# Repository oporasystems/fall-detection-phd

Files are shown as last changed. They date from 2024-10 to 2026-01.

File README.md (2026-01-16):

# Fall Detection System

A transformer-based fall detection system combining IoT sensors (Raspberry Pi + MPU6050 accelerometer) with deep learning for real-time fall classification. This project was developed as part of PhD research comparing multiple transformer architectures for time-series classification.

## Overview

The system collects accelerometer data at 100Hz, processes it through trained neural network models, and triggers alerts via a GPIO-connected buzzer when a fall is detected. After extensive comparison of 10 different transformer variants, the **Performer** architecture was selected for production deployment due to its optimal balance of accuracy and inference speed on embedded hardware.

### Key Features

- Real-time fall detection on Raspberry Pi Zero 2W
- 100Hz accelerometer sampling with Butterworth filtering
- Binary classification (Fall vs Activities of Daily Living)
- Sub-5MB model size for embedded deployment
- Audible alerts via piezo buzzer

## Hardware Requirements

| Component | Description |
|---|---|
| Raspberry Pi Zero 2W | Main processing unit |
| MPU6050 | 6-axis accelerometer/gyroscope (I2C address 0x68) |
| BMP388 | Barometric pressure sensor (for altitude) |
| Piezo Buzzer | Connected to GPIO 23 |
| Push Buttons | GPIO 24 (tracking on/off), GPIO 25 (alert on/off) |

### Wiring Diagram

```
MPU6050:
  VCC -> 3.3V
  GND -> GND
  SDA -> GPIO 2 (SDA)
  SCL -> GPIO 3 (SCL)

BMP388:
  VCC -> 3.3V
  GND -> GND
  SDA -> GPIO 2 (SDA)
  SCL -> GPIO 3 (SCL)

Buzzer:
  + -> GPIO 23
  - -> GND

Buttons:
  Button 1 -> GPIO 24 (with pull-up)
  Button 2 -> GPIO 25 (with pull-up)
```

## Quick Start (Raspberry Pi)

### 1. Install Dependencies

```bash
sudo apt install -y i2c-tools python3-pip
pip install pandas smbus numpy scikit-learn torch scipy RPi.GPIO \
    board Adafruit-Blinka adafruit-circuitpython-bmp3xx performer-pytorch \
    --break-system-packages
```

### 2. Enable I2C

```bash
sudo raspi-config
# Navigate to: Interface Options -> I2C -> Enable
```

### 3. Verify Sensors

```bash
i2cdetect -y 1
# Should show devices at 0x68 (MPU6050) and 0x77 (BMP388)
```

### 4. Deploy Model and Config Files

Copy to your Raspberry Pi:
- `performer_model.pt` -> `/home/ivanursul/performer_model.pt`
- `mpu_offsets.json` -> `/home/ivanursul/mpu_offsets.json`

### 5. Run Fall Detector

```bash
python3 iot/pi/fall-detector.py
```

### 6. Setup as Systemd Service (Optional)

Create service file:
```bash
sudo nano /etc/systemd/system/fall-detector.service
```

Contents:
```ini
[Unit]
Description=Fall Detection Service
After=network.target

[Service]
ExecStart=/usr/bin/python3 /home/ivanursul/fall-detector.py
Restart=always
WorkingDirectory=/home/ivanursul
Environment="PYTHONUNBUFFERED=1"

[Install]
WantedBy=multi-user.target
```

Enable and start:
```bash
sudo systemctl daemon-reload
sudo systemctl enable fall-detector.service
sudo systemctl start fall-detector.service
```

Check status:
```bash
sudo systemctl status fall-detector.service
journalctl -u fall-detector.service --no-pager --lines=50
```

## Project Structure

```
fall-detection-phd/
├── config.yaml                 # Base configuration (committed)
├── config.local.yaml.example   # Template for local overrides
├── deploy/                         # Deployment scripts
│   ├── common.sh                   # Shared deployment functions
│   ├── deploy-fall-detector.sh     # Deploy production fall detection
│   ├── deploy-adl-collector.sh     # Deploy ADL data collector
│   ├── deploy-fall-collector.sh    # Deploy fall data collector
│   └── logs.sh                     # View logs from Pi remotely
├── iot/
│   ├── pi/
│   │   ├── fall-detector.py        # Production fall detection (uses Performer)
│   │   ├── data-collector-adl.py   # Collect ADL (daily activities) data
│   │   ├── data-collector-falls.py # Collect fall data with timing heatmap
│   │   ├── calibrate-mpu-6050.py   # Sensor calibration utility
│   │   ├── logging_config.py       # Shared logging configuration
│   │   └── debug/                  # Debugging utilities
│   └── arduino/
│       └── converter/              # TFLite model conversion
├── training/
│   ├── models/                     # Model architecture definitions
│   │   ├── transformer.py          # Base transformer
│   │   ├── performer.py            # Performer (PRODUCTION MODEL)
│   │   ├── informer.py             # Sparse attention
│   │   ├── linformer.py            # Linear complexity
│   │   ├── multi_scale_transformer.py
│   │   ├── temporal_convolutional_transformer.py
│   │   ├── lstm_transformer.py
│   │   ├── t2v_bert.py             # Time2Vec + BERT
│   │   └── transformer_laurel.py   # LAuReL residual enhancement
│   ├── variations/                 # Training scripts per model
│   │   ├── performer/              # Performer training & tuning
│   │   ├── transformer/
│   │   ├── informer/
│   │   └── ...                     # Other variants
│   ├── experiments/                # Model comparison experiments
│   └── utils/
│       ├── constants.py            # Configuration loader
│       ├── dataset_utils.py        # Dataset loading
│       ├── train_utils.py          # Training utilities
│       └── logging_utils.py        # Logging setup
├── dataset/
│   ├── review/                     # Dataset review utilities
│   ├── visualisation/              # Visualization scripts
│   └── video/                      # Video-based dataset tools
├── 3d-models/                      # OpenSCAD enclosure designs
├── pcb/                            # Circuit board designs
└── docs/
    └── plans/                      # Design documents
```

## Model Architectures

This project implements and compares 10 transformer variants for fall detection:

| Model | Description | Key Feature |
|---|---|---|
| **Performer** | Kernel-based efficient attention | **Selected for production** - best accuracy/speed tradeoff |
| Transformer | Standard multi-head attention | Baseline implementation |
| Informer | ProbSparse self-attention | Reduced complexity for long sequences |
| Linformer | Linear complexity attention | O(n) instead of O(n²) |
| Multi-Scale | Multi-resolution processing | Captures patterns at different time scales |
| TCN-Transformer | Temporal convolution + transformer | Hybrid architecture |
| LSTM-Transformer | LSTM + transformer | Combines recurrent and attention |
| T2V-BERT | Time2Vec + BERT | Learned time representations |
| LAuReL | Residual enhancement | Latest experimental addition |
| Reformer | Local sensitive hashing | Memory-efficient attention |

### Why Performer?

After hyperparameter tuning with Optuna and comparison experiments, Performer was selected because:
1. Achieves comparable accuracy to standard transformer
2. Significantly faster inference on Raspberry Pi
3. Model size under 5MB constraint for embedded deployment
4. Stable training with good generalization

## Training Pipeline

### Dataset Format

The system expects CSV files with accelerometer data:
- **Columns**: `AccX_filtered_i`, `AccY_filtered_i`, `Corrected_AccZ_i`, `Acc_magnitude_i`
- **Sequence length**: 800 timesteps (8 seconds at 100Hz)
- **Labels**: Binary (0 = Non-Fall/ADL, 1 = Fall)

### Configuration

1. Copy the example config:
   ```bash
   cp config.local.yaml.example config.local.yaml
   ```

2. Edit `config.local.yaml` with your dataset paths:
   ```yaml
   dataset:
     fall_folder: "/path/to/your/Fall/data"
     non_fall_folder: "/path/to/your/ADL/data"
   ```

### Training a Model

```bash
# Train Performer model
python3 training/variations/performer/performer-model.py

# Run hyperparameter tuning
python3 training/variations/performer/performer-hyperparameter-tuning.py
```

### Model Comparison

The `training/experiments/transformer-variation-comparison/` directory contains scripts to evaluate all models on the same dataset, measuring:
- Accuracy, Precision, Recall, F1-score
- Inference latency
- Memory usage
- Model size

## Data Collection

### Activities of Daily Living (ADL)

```bash
python3 iot/pi/data-collector-adl.py
```

Collects 8-second windows of normal daily activities. Press the button (GPIO 24) to start/stop recording.

### Fall Data

```bash
python3 iot/pi/data-collector-falls.py
```

Collects fall event data with an intelligent timing system:
- Maintains a heatmap of when falls occur within the 8-second window
- Beeps to signal when to perform the fall
- Ensures balanced dataset distribution across all 100ms intervals

This approach prevents bias in fall timing and improves model generalization.

## Deployment

Automated deployment scripts make it easy to set up Raspberry Pi devices for your team.

### Prerequisites

Install `sshpass` on your local machine for automated SSH:

```bash
# macOS
brew install hudochenkov/sshpass/sshpass

# Ubuntu/Debian
sudo apt install sshpass
```

### Deploy Fall Detector (Production)

```bash
./deploy/deploy-fall-detector.sh
```

Deploys real-time fall detection:
- Uploads `fall-detector.py` and trained Performer model
- Runs sensor calibration
- Sets up auto-start systemd service

### Deploy ADL Data Collector

```bash
./deploy/deploy-adl-collector.sh
```

Deploys data collection for normal daily activities:
- Uploads `data-collector-adl.py`
- Runs sensor calibration
- Sets up systemd service

### Deploy Fall Data Collector

```bash
./deploy/deploy-fall-collector.sh
```

Deploys data collection for fall events:
- Uploads `data-collector-falls.py` and timing heatmap
- Runs sensor calibration
- Sets up systemd service

### Switching Modes

Only one mode can be active at a time. Deploying a new mode automatically stops and replaces the previous one:

1. Deploy `fall-collector` → collect fall data
2. Deploy `adl-collector` → collect daily activity data
3. Retrain model with new data
4. Deploy `fall-detector` → back to production

### Calibration

During deployment, you'll be prompted to position the device:

1. Place the device on a **flat, level surface**
2. Keep it **completely stationary**
3. Press ENTER to start calibration

The calibration measures accelerometer bias and saves offsets to `mpu_offsets.json`.

### Viewing Logs

Logs are stored in `~/logs/fall-detection.log` with daily rotation (30 days retention).

```bash
# View logs interactively
./deploy/logs.sh

# Follow logs in real-time
./deploy/logs.sh -f

# Show last 500 lines
./deploy/logs.sh -n 500

# Show logs from specific date
./deploy/logs.sh -d 2024-01-15
```

### Managing Services

```bash
# Check status
ssh pi@<IP> 'systemctl status fall-detector'

# Restart
ssh pi@<IP> 'sudo systemctl restart fall-detector'

# Stop
ssh pi@<IP> 'sudo systemctl stop fall-detector'
```

## Configuration Reference

### config.yaml

| Section | Key | Description |
|---|-----|---|
| `dataset.fall_folder` | Path to fall data CSVs |
| `dataset.non_fall_folder` | Path to ADL data CSVs |
| `model.max_sequence_length` | Input sequence length (default: 800) |
| `model.input_dim` | Number of input features (default: 4) |
| `model.num_classes` | Classification classes (default: 2) |
| `raspberry_pi.model_path` | Path to deployed model on Pi |
| `hardware.sampling_rate` | Sensor sampling rate (default: 100Hz) |

### config.local.yaml

Create this file (gitignored) to override base settings for your environment. Only include values that differ from the base config.

## Troubleshooting

### I2C Device Not Found

```bash
# Check if I2C is enabled
ls /dev/i2c*

# Scan for devices
i2cdetect -y 1
```

If devices aren't detected:
1. Check wiring connections
2. Ensure I2C is enabled in raspi-config
3. Verify pull-up resistors on SDA/SCL lines

### Model Loading Errors

- Ensure PyTorch version matches between training and deployment
- Verify model file path in config or fall-detector.py
- Check available memory on Raspberry Pi

### Buzzer Not Sounding

- Verify GPIO 23 connection
- Check if GPIO is being used by another process
- Test with a simple GPIO script

### High CPU Usage

The fall detector runs continuously. On Raspberry Pi Zero 2W:
- CPU usage ~60-80% during inference is normal
- Consider reducing sampling rate if overheating occurs

## License

This project was developed as part of PhD research. Please contact the author for licensing information.

## Citation

If you use this work in your research, please cite:
```
[Citation information to be added]
```

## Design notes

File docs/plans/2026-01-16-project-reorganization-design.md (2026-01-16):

# Fall Detection Project Reorganization Design

**Date:** 2026-01-16
**Status:** Approved
**Goal:** Archive cleanup, production focus, and team-ready GitHub release

## Context

This is a completed PhD project for transformer-based fall detection using Raspberry Pi and MPU6050 accelerometer. The **Performer** model was selected as the best-performing architecture and is deployed in production (`iot/pi/fall-detector.py`).

The project needs cleanup for:
- Academic archival (thesis/publication ready)
- Production deployment (Raspberry Pi)
- Team collaboration (GitHub release)

## Decisions Made

| Decision | Choice | Rationale |
|---|---|---|
| Chosen model | Performer | Best performance, already in production |
| Other model variants | Keep all | Preserve research history for reproducibility |
| IoT script refactoring | No | No tests, working code, risk of breaking |
| Path configuration | Config file (base + local override) | Team-friendly, explicit |
| Documentation | Full README | Comprehensive for onboarding |
| Reorganization scope | Quick wins only | Minimal disruption |

## Implementation Plan

### 1. Quick Win Fixes

#### 1.1 Remove duplicate code
- `training/models/multi_scale_transformer.py`: Delete duplicate `PositionalEncoding` class (lines 27-45)
- `training/utils/train_utils.py`: Remove duplicate `train_model()` function (lines 95-129)

#### 1.2 Update `.gitignore`
Add:
```
venv/
*.zip
.DS_Store
__pycache__/
*.pyc
config.local.yaml
```

#### 1.3 File naming
- Keep existing names as-is (no renaming)
- Document convention for future files: use underscores for Python files

### 2. Config File System

#### 2.1 Create `config.yaml` (committed)
Base config with defaults:
```yaml
# Base configuration - override in config.local.yaml
dataset:
  fall_folder: "./data/Fall"
  non_fall_folder: "./data/ADL"

raspberry_pi:
  model_path: "/home/ivanursul/performer_model.pt"
  offsets_path: "/home/ivanursul/mpu_offsets.json"
  data_output_path: "/home/ivanursul/accelerometer_data_raw"
```

#### 2.2 Create `config.local.yaml.example`
Template for personal overrides:
```yaml
# Copy to config.local.yaml and customize
dataset:
  fall_folder: "/your/path/to/Fall"
  non_fall_folder: "/your/path/to/ADL"
```

#### 2.3 Update `training/utils/constants.py`
Load base config, merge local overrides if present.

### 3. Documentation (README.md)

Structure:
1. Overview - Project description, key features
2. Hardware Requirements - Pi Zero 2W, MPU6050, BMP388, buzzer, buttons
3. Quick Start - Installation, systemd setup, running fall-detector.py
4. Project Structure - Directory tree with descriptions
5. Model Architectures - All 10 variants, why Performer was selected
6. Training Pipeline - Dataset format, training, hyperparameter tuning
7. Data Collection - ADL and falls scripts, heatmap system
8. Configuration - config.yaml vs config.local.yaml
9. Troubleshooting - Common issues

## What Stays Unchanged

- `iot/pi/data-collector-adl.py` - no refactoring
- `iot/pi/data-collector-falls.py` - no refactoring
- `iot/pi/fall-detector.py` - no refactoring
- Folder structure - no reorganization
- All 10 model variants - preserved as-is
- Existing file names - no renaming
- Training pipeline logic - unchanged

## Implementation Order

1. Fix `.gitignore` (prevents committing junk)
2. Remove duplicate code (quick fixes)
3. Add config file system
4. Write comprehensive README

## Deliverables

- Clean codebase with no duplicate code
- Config-based path management for team use
- Comprehensive README for onboarding
- All 10 model variants preserved with documentation

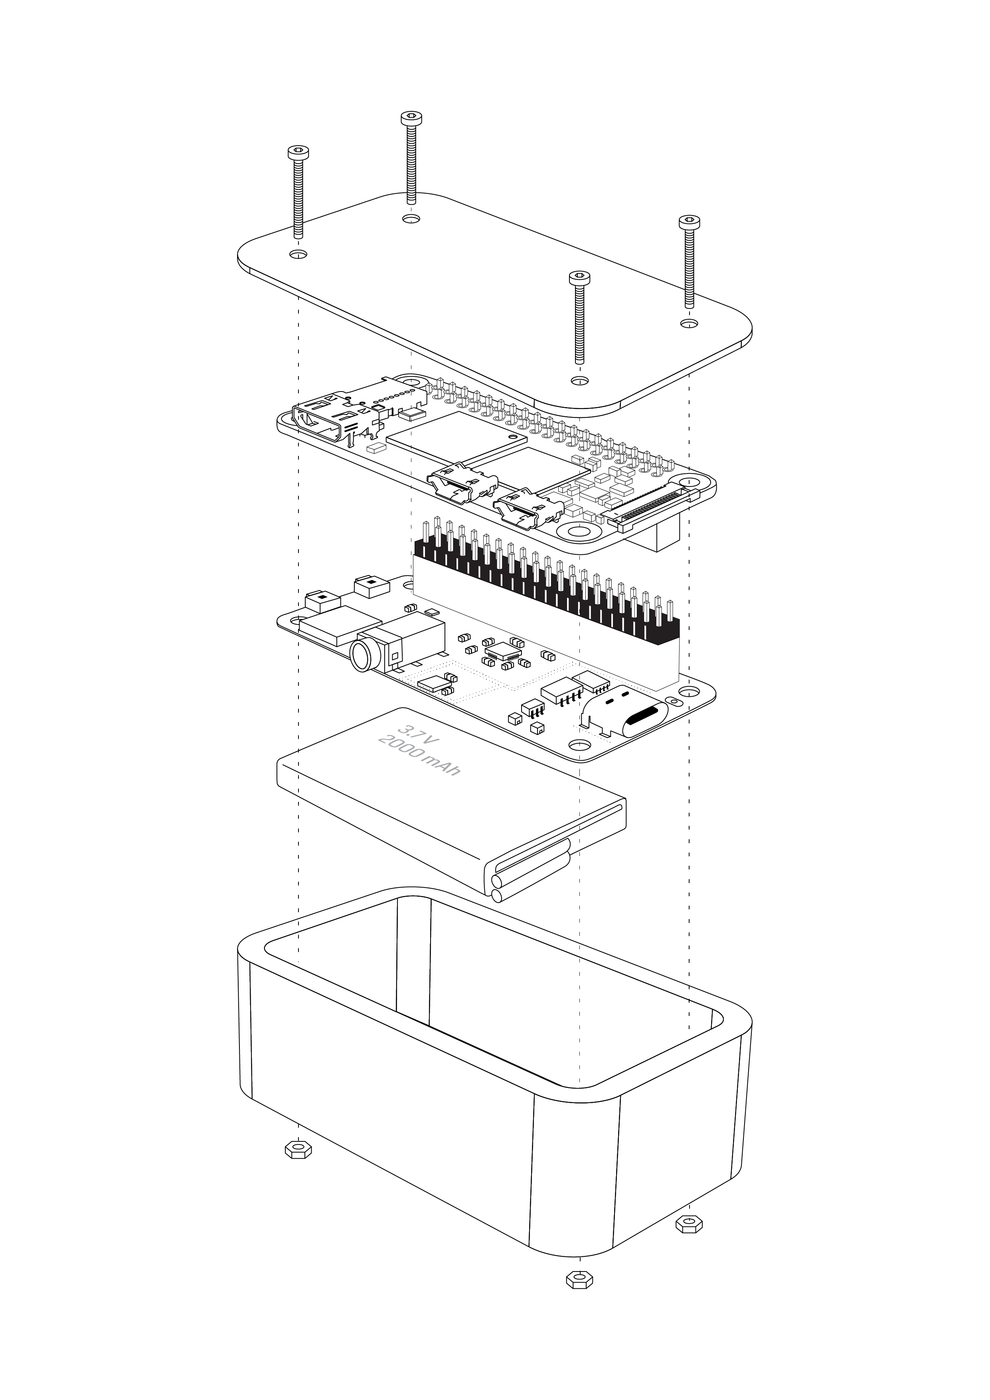
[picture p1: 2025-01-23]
Geriatric device-02.png

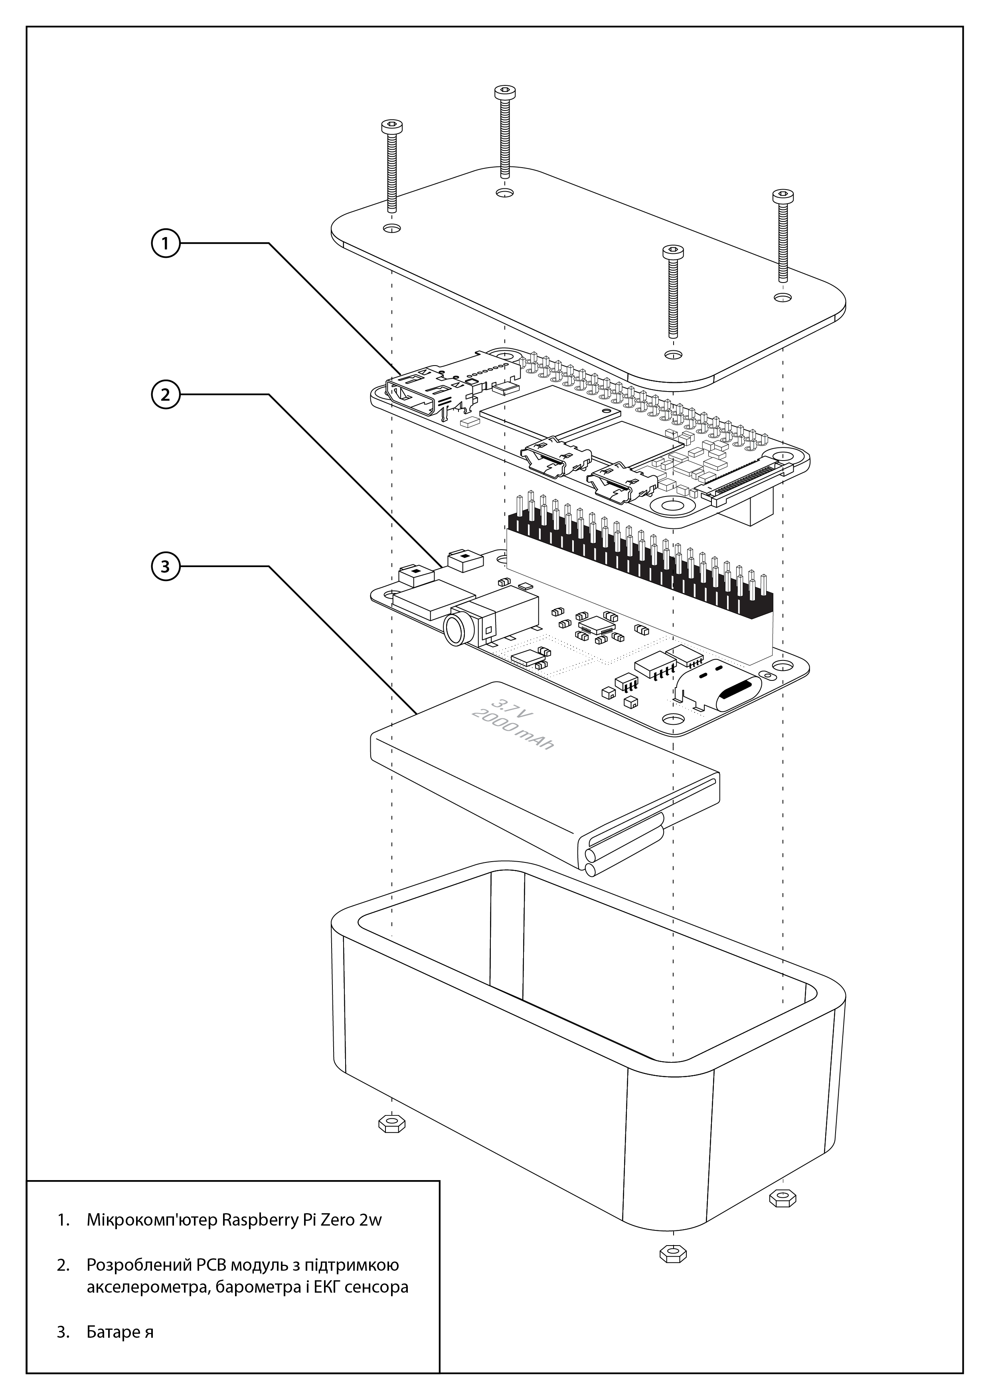
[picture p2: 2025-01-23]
Geriatric device-01.png

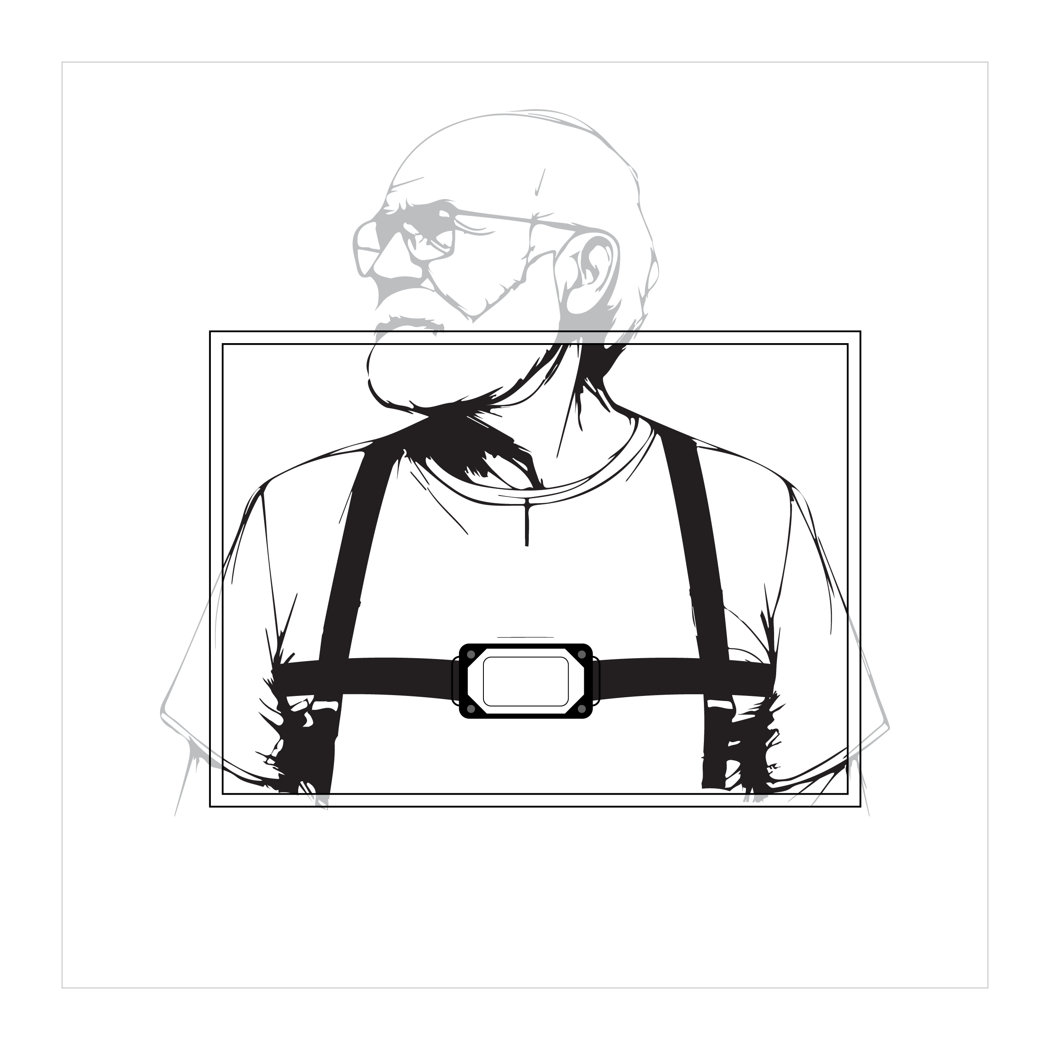
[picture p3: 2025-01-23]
Geriatric device-03.png

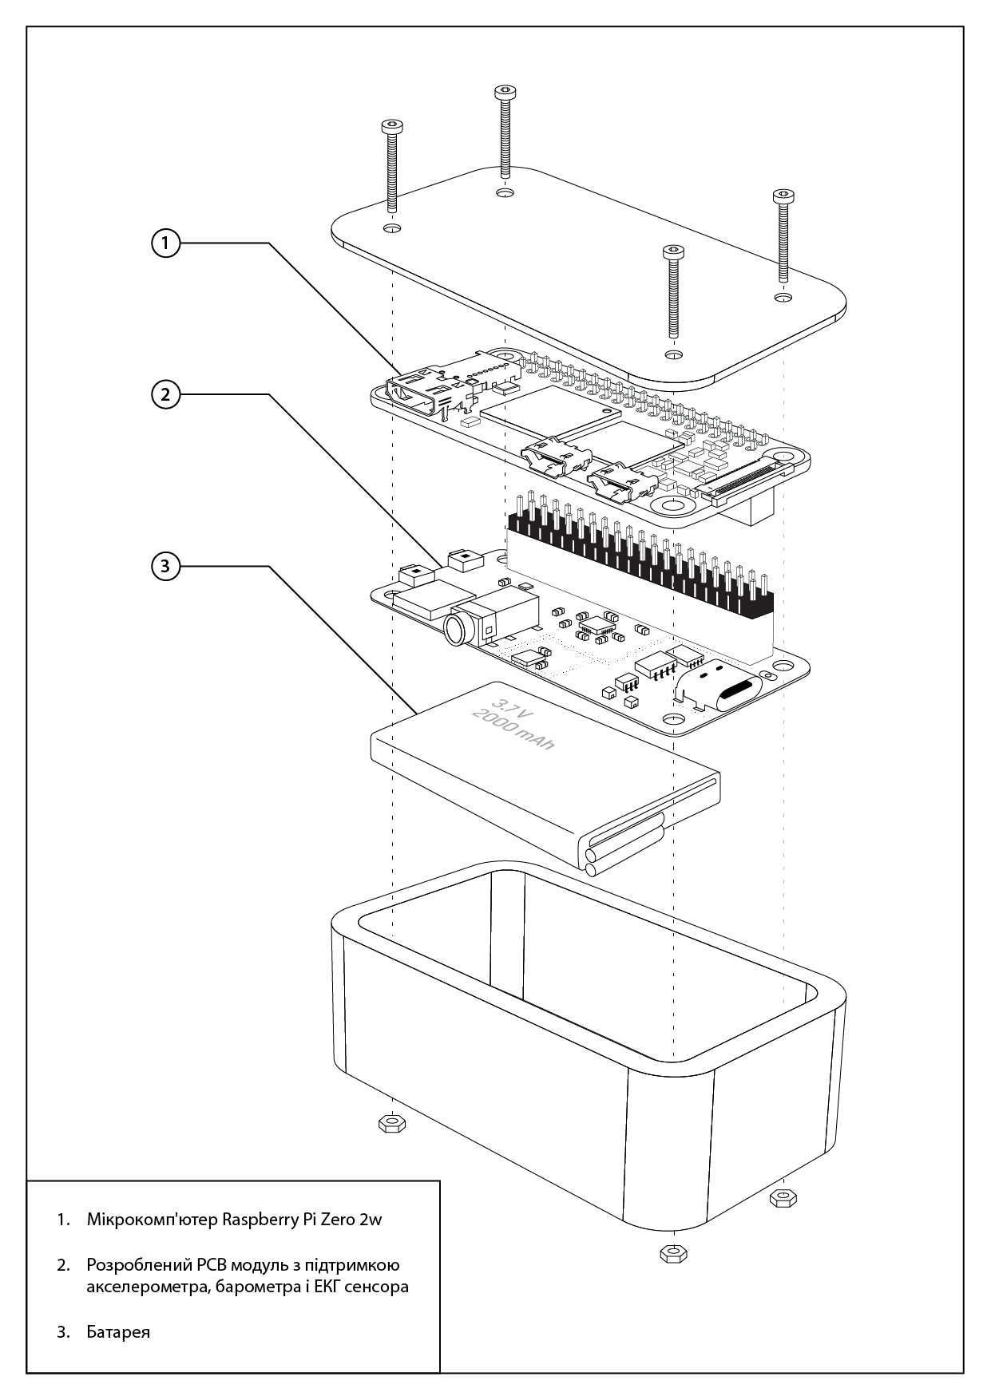
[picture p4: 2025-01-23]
patent blueprint-01.png

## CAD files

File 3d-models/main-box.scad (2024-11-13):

// Parameters
length = 76;            // Outer length of the box
width = 40;             // Outer width of the box
height = 25;            // Height of the box
wall_thickness = 2;     // Thickness of the walls (returned to 2mm)
corner_radius = 5;      // Radius of the outer corners

// USB Type-C hole parameters
usb_width = 10;         // Width of the USB Type-C hole
usb_height = 4;         // Height of the USB Type-C hole
usb_corner_radius = 1;  // Corner radius for the USB hole (optional)
usb_position_y = 0;     // Y position (centered vertically on the side wall)
usb_position_z = wall_thickness + usb_height / 2 + 10; // Near bottom edge

// Push button hole parameters
button_size = 6;        // Size of the push button holes (6mm x 6mm)
button1_position_x = -length / 4;  // Position of the first button hole
button2_position_x = length / 4;   // Position of the second button hole
button_position_z = (height / 2);    // Centered vertically

// New hole parameters
new_hole_width = 13;        // Width of the new hole (along the x-axis)
new_hole_height = 9;      // Height of the new hole (along the z-axis)
new_hole_position_x = 0;   // Position of the new hole along the x-axis (centered between existing holes)
new_hole_position_z = button_position_z + 3; // Vertical position (same as existing holes)

// Tolerance for proper subtraction
epsilon = 0.1;          // Small offset to ensure clean subtraction

// Calculate inner_corner_radius and handle corner_radius < wall_thickness
if (corner_radius < wall_thickness) {
    echo("Error: corner_radius must be greater than or equal to wall_thickness");
    corner_radius = wall_thickness; // Set corner_radius to wall_thickness to avoid negative values
}
inner_corner_radius = corner_radius - wall_thickness;

difference() {
    // Outer box with rounded corners
    linear_extrude(height)
        rounded_rectangle(length, width, corner_radius);

    // Inner box to create the hollow space
    translate([0, 0, wall_thickness])
        linear_extrude(height - wall_thickness)
            rounded_rectangle(length - 2 * wall_thickness, width - 2 * wall_thickness, inner_corner_radius);

    // USB Type-C hole on the longer side, near the bottom edge
    translate([length / 2 + epsilon, usb_position_y, usb_position_z])
        rotate([0, 0, 90]) // Rotate to align with the side wall
            usb_hole();

    // Push button holes on one of the sides
    // First button hole
    translate([button1_position_x, width / 2 + epsilon, button_position_z])
        cube([button_size, width + 2 * epsilon, button_size], center=true);

    // Second button hole
    translate([button2_position_x, width / 2 + epsilon, button_position_z])
        cube([button_size, width + 2 * epsilon, button_size], center=true);

    // New rectangular hole between the two existing holes
    translate([new_hole_position_x, width / 2 + epsilon, new_hole_position_z])
        cube([new_hole_width, width + 2 * epsilon, new_hole_height], center=true);
}

// Module to create a rounded rectangle
module rounded_rectangle(len, wid, rad) {
    rad = min(rad, len / 2, wid / 2); // Ensure radius does not exceed half the length or width
    offset(r=rad)
        square([len - 2 * rad, wid - 2 * rad], center=true);
}

// Module for the USB Type-C hole
module usb_hole() {
    if (usb_corner_radius > 0) {
        minkowski() {
            cube([usb_width - 2 * usb_corner_radius, usb_height - 2 * usb_corner_radius, wall_thickness + 2 * epsilon], center=true);
            sphere(r=usb_corner_radius);
        }
    } else {
        cube([usb_width, usb_height, wall_thickness + 2 * epsilon], center=true);
    }
}

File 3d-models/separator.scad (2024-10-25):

// Box parameters (should match your existing box parameters)
length = 76;             // Outer length of the box
width = 37;              // Outer width of the box
wall_thickness = 2;      // Thickness of the walls
corner_radius = 5;       // Radius of the outer corners

// Separator parameters
separator_thickness = 2;           // Thickness of the separator
separator_clearance = 0.2;         // Clearance for proper fit

// Pillar parameters
pillar_radius = 2;               // Radius of the pillars
pillar_height = 12;                // Height of the pillars (as per your request)
pillar_margin = 1;                 // Margin from the edges

// Ventilation parameters
vent_line_width = 1;               // Width of the ventilation lines (made thinner)
vent_line_spacing = 3;             // Spacing between lines (center to center)

// Inner dimensions of the box
inner_length = length - 2 * wall_thickness;
inner_width  = width - 2 * wall_thickness;

// Inner corner radius
inner_corner_radius = corner_radius - wall_thickness;

// Separator dimensions
separator_length = inner_length - 2 * separator_clearance;
separator_width  = inner_width - 2 * separator_clearance;
separator_radius = inner_corner_radius - separator_clearance;

// Hole dimensions
hole_length = 56;  // Length of the hole
hole_width = 8;    // Width of the hole

// Create the separator with ventilation lines, pillars, and hole
module separator_with_ventilation_lines_and_pillars() {
    difference() {
        // Separator plate
        translate([0, 0, 0])
            linear_extrude(separator_thickness)
                rounded_rectangle(separator_length, separator_width, separator_radius);

        // Ventilation lines (code for this can be added as needed)

        // Subtract the hole
        translate([0, separator_width/2 - hole_width/2, 0])  // Centered along length, aligned to the edge on width
            linear_extrude(separator_thickness)
                square([hole_length, hole_width + 1], center = true);
    }

    // Pillars
    // Positions for the pillars (stepped back by pillar_margin from the edges)
    positions = [
        [ separator_length / 2 - pillar_margin - pillar_radius,  separator_width / 2 - pillar_margin - pillar_radius],
        [-separator_length / 2 + pillar_margin + pillar_radius,  separator_width / 2 - pillar_margin - pillar_radius],
        [-separator_length / 2 + pillar_margin + pillar_radius, -separator_width / 2 + pillar_margin + pillar_radius],
        [ separator_length / 2 - pillar_margin - pillar_radius, -separator_width / 2 + pillar_margin + pillar_radius]
    ];

    // Create pillars at each corner, connected to the separator
    for (pos = positions) {
        translate([pos[0], pos[1], -pillar_height])
            pillar(pillar_radius, pillar_height + separator_thickness);
    }
}

// Module to create a rounded rectangle
module rounded_rectangle(len, wid, rad) {
    rad = min(rad, len / 2, wid / 2); // Ensure radius does not exceed half the length or width
    offset(r = rad)
        square([len - 2 * rad, wid - 2 * rad], center = true);
}

// Module to create a pillar (cylinder)
module pillar(radius, height) {
    cylinder(h = height, r = radius, center = false);
}

// Render the separator with ventilation lines, pillars, and hole
separator_with_ventilation_lines_and_pillars();

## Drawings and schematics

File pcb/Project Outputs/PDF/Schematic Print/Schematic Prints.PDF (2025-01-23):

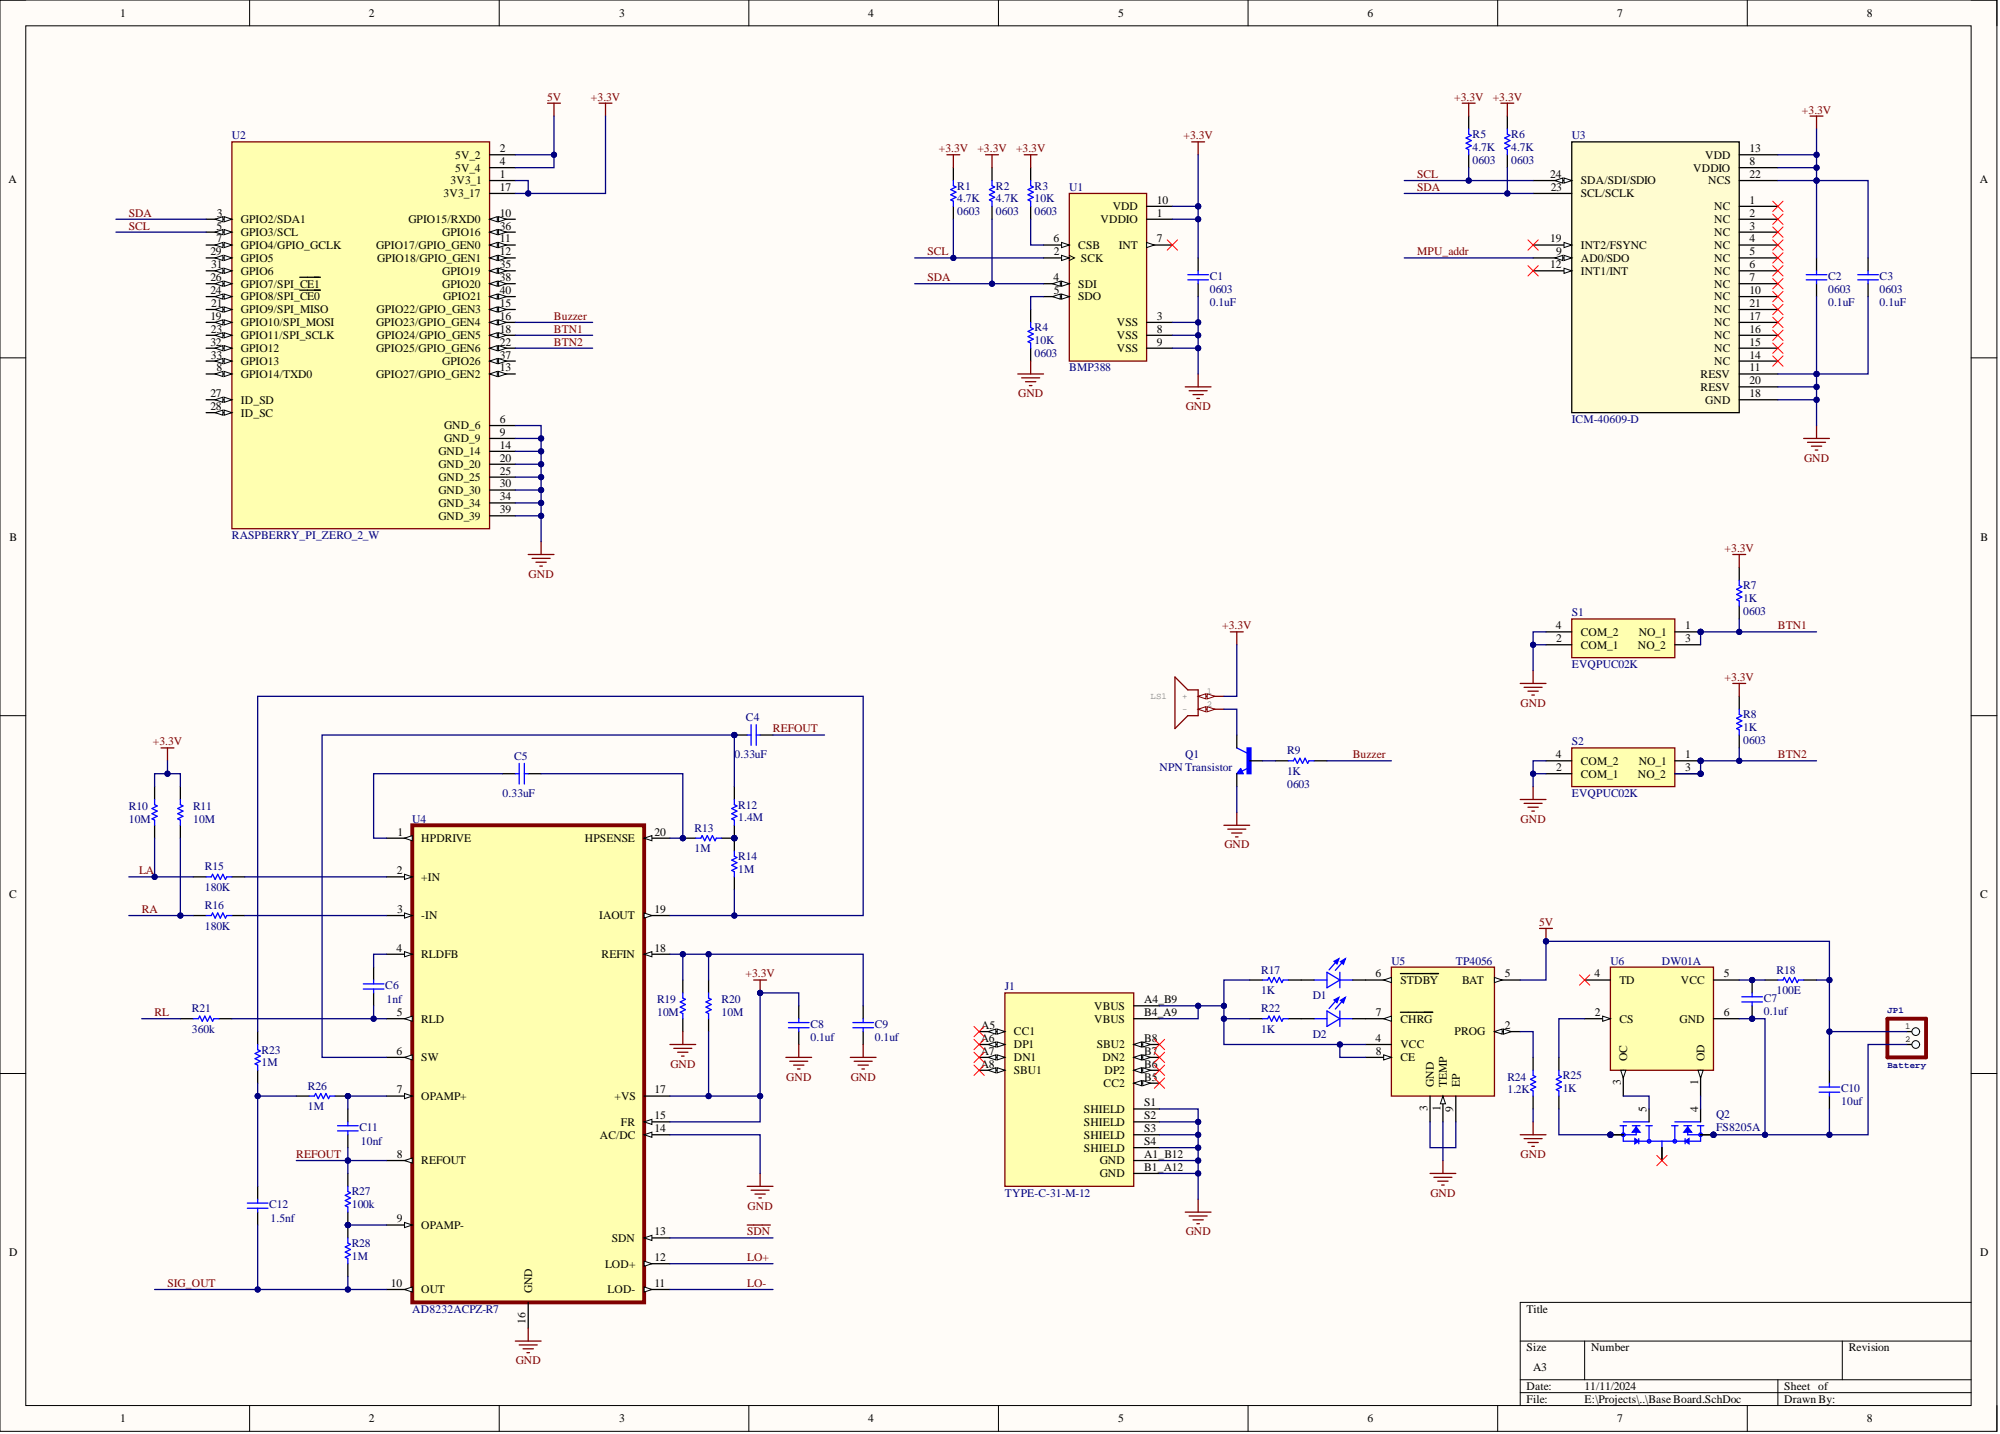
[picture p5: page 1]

C6 | RLD 5 SW 6 | R19 10M | +3.3V

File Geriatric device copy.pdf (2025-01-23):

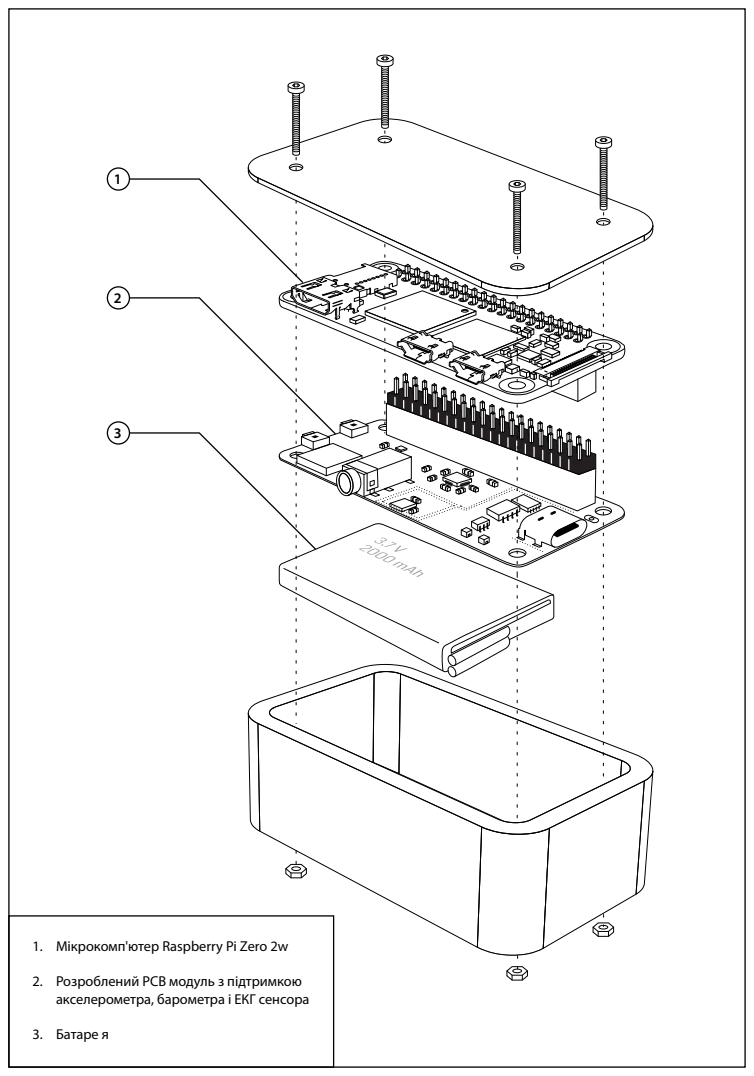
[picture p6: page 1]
3. Батаре я

1. Мікрокомп'ютер Raspberry Pi Zero 2w

2. Розроблений PCB модуль з підтримкою
акселерометра, барометра і ЕКГ сенсора

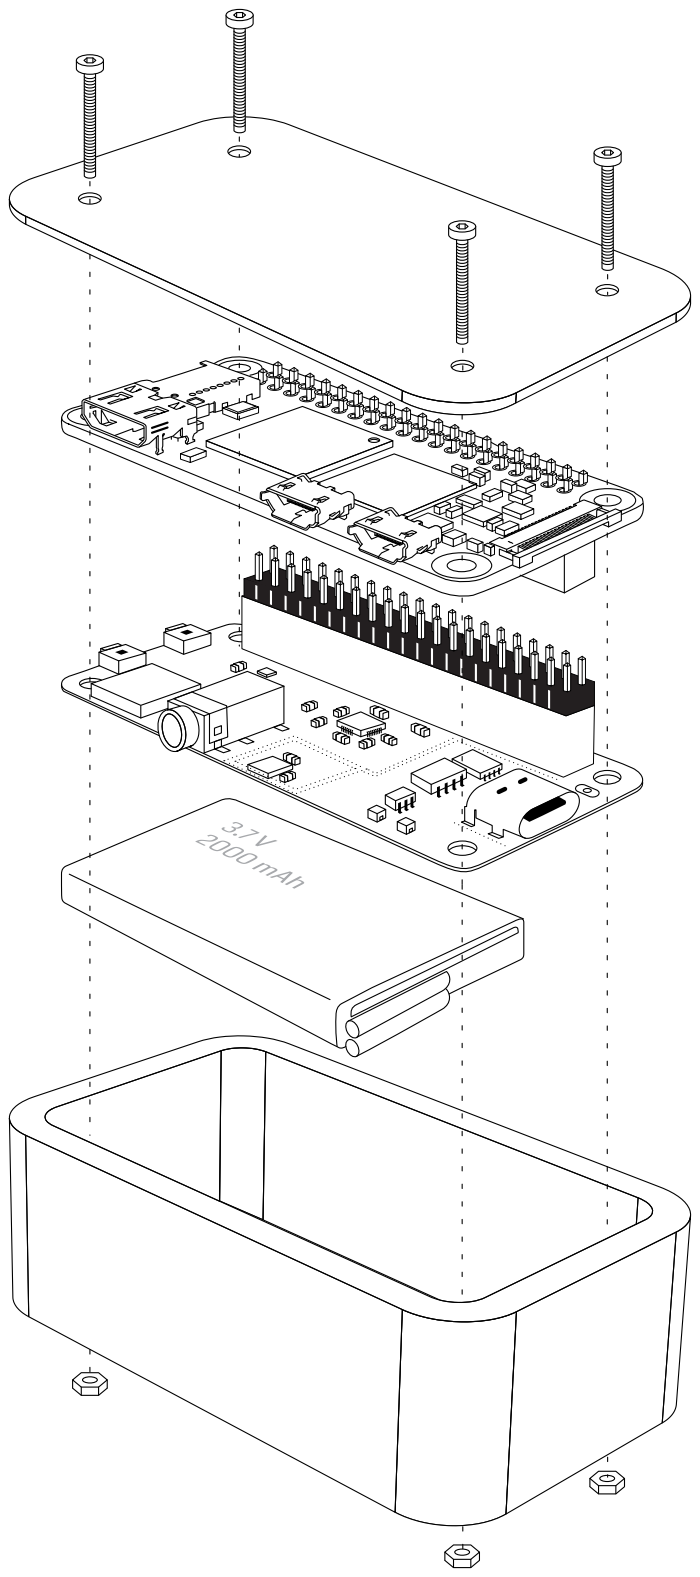
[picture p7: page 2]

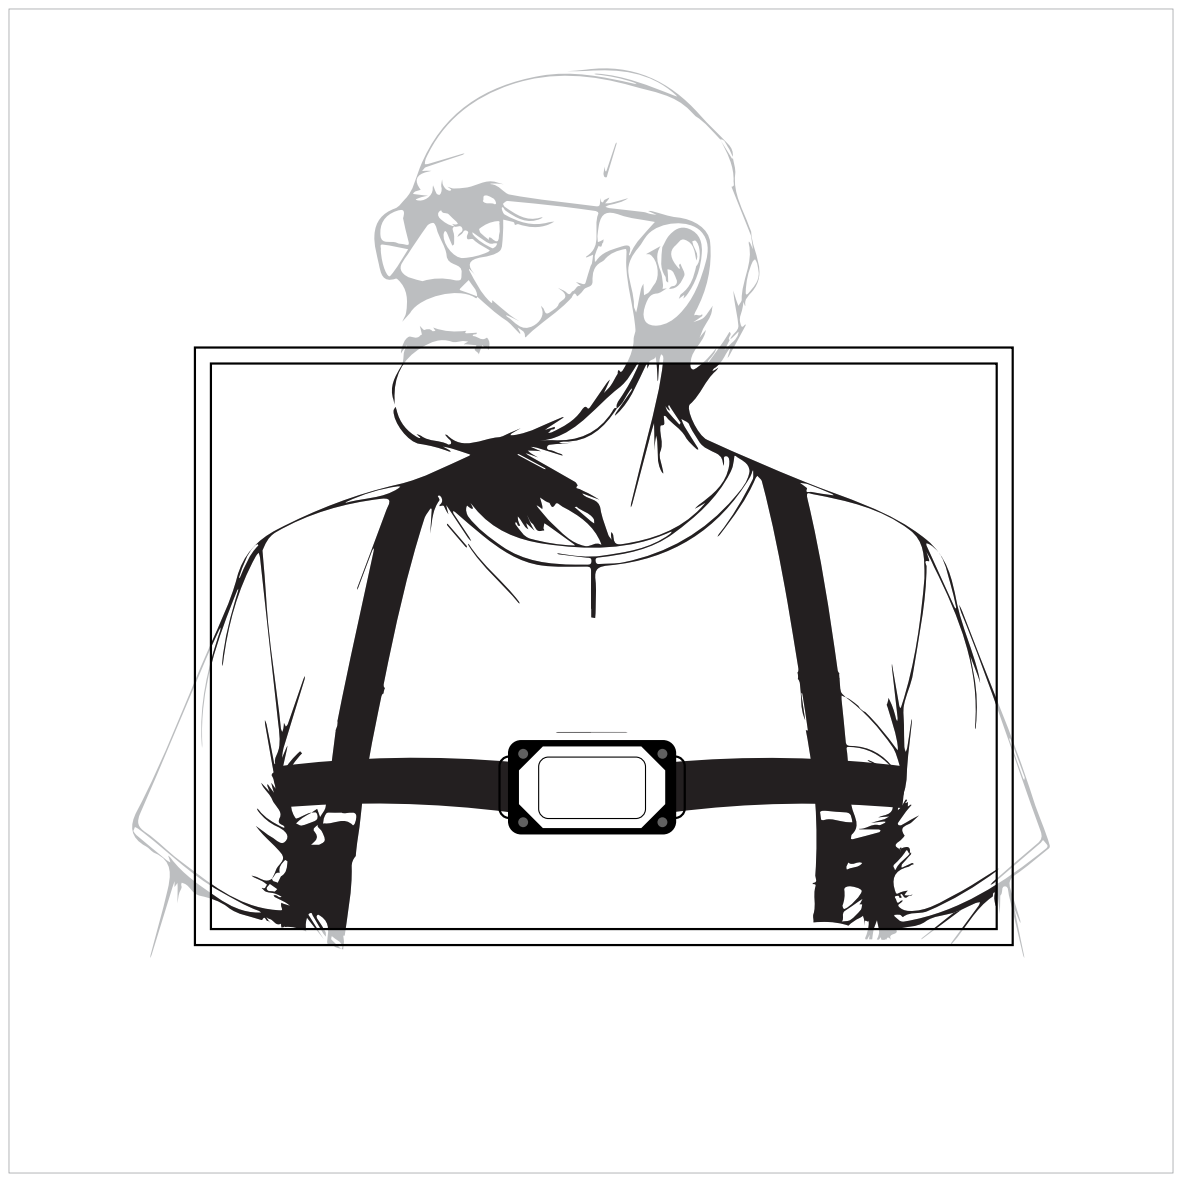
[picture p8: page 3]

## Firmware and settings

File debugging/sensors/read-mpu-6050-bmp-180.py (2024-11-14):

import smbus
import time

# MPU6050 and BMP180 addresses
MPU6050_ADDR = 0x68
BMP180_ADDR = 0x77

# MPU6050 Registers
MPU6050_PWR_MGMT_1 = 0x6B
MPU6050_ACCEL_XOUT_H = 0x3B
MPU6050_ACCEL_YOUT_H = 0x3D
MPU6050_ACCEL_ZOUT_H = 0x3F

# BMP180 Registers
BMP180_CONTROL = 0xF4
BMP180_TEMPDATA = 0xF6
BMP180_PRESSUREDATA = 0xF6
BMP180_READTEMPCMD = 0x2E
BMP180_READPRESSURECMD = 0x34

# I2C bus
bus = smbus.SMBus(1)


# Function to read raw data from MPU6050
def read_mpu6050_raw_data(register):
    high = bus.read_byte_data(MPU6050_ADDR, register)
    low = bus.read_byte_data(MPU6050_ADDR, register + 1)
    value = (high << 8) | low
    if value > 32767:
        value = value - 65536
    return value


# Initialize MPU6050
def initialize_mpu6050():
    bus.write_byte_data(MPU6050_ADDR, MPU6050_PWR_MGMT_1, 0)


# Read accelerometer data
def read_accelerometer_data():
    acc_x = read_mpu6050_raw_data(MPU6050_ACCEL_XOUT_H)
    acc_y = read_mpu6050_raw_data(MPU6050_ACCEL_YOUT_H)
    acc_z = read_mpu6050_raw_data(MPU6050_ACCEL_ZOUT_H)

    # Convert to g values (assuming range is +/- 2g, scale factor is 16384)
    acc_x = acc_x / 16384.0
    acc_y = acc_y / 16384.0
    acc_z = acc_z / 16384.0

    return acc_x, acc_y, acc_z


# Read calibration data from BMP180
def read_bmp180_calibration_data():
    cal = {}
    cal['AC1'] = read_signed_16_bit(BMP180_ADDR, 0xAA)
    cal['AC2'] = read_signed_16_bit(BMP180_ADDR, 0xAC)
    cal['AC3'] = read_signed_16_bit(BMP180_ADDR, 0xAE)
    cal['AC4'] = read_unsigned_16_bit(BMP180_ADDR, 0xB0)
    cal['AC5'] = read_unsigned_16_bit(BMP180_ADDR, 0xB2)
    cal['AC6'] = read_unsigned_16_bit(BMP180_ADDR, 0xB4)
    cal['B1'] = read_signed_16_bit(BMP180_ADDR, 0xB6)
    cal['B2'] = read_signed_16_bit(BMP180_ADDR, 0xB8)
    cal['MB'] = read_signed_16_bit(BMP180_ADDR, 0xBA)
    cal['MC'] = read_signed_16_bit(BMP180_ADDR, 0xBC)
    cal['MD'] = read_signed_16_bit(BMP180_ADDR, 0xBE)
    return cal


def read_signed_16_bit(address, register):
    high = bus.read_byte_data(address, register)
    low = bus.read_byte_data(address, register + 1)
    value = (high << 8) + low
    if value > 32767:
        value = value - 65536
    return value


def read_unsigned_16_bit(address, register):
    high = bus.read_byte_data(address, register)
    low = bus.read_byte_data(address, register + 1)
    value = (high << 8) + low
    return value


# Read temperature and calculate B5
def read_bmp180_temperature(cal):
    bus.write_byte_data(BMP180_ADDR, BMP180_CONTROL, BMP180_READTEMPCMD)
    time.sleep(0.005)  # Wait for converter
    UT = read_unsigned_16_bit(BMP180_ADDR, BMP180_TEMPDATA)

    # Calculate true temperature using calibration data
    X1 = ((UT - cal['AC6']) * cal['AC5']) // (1 << 15)
    X2 = (cal['MC'] * (1 << 11)) // (X1 + cal['MD'])
    B5 = X1 + X2
    temperature = (B5 + 8) // (1 << 4)

    return temperature / 10.0, B5  # In degrees Celsius


# Calculate true pressure
def read_bmp180_pressure(cal, B5):
    OSS = 3  # Oversampling setting
    bus.write_byte_data(BMP180_ADDR, BMP180_CONTROL, BMP180_READPRESSURECMD + (OSS << 6))
    time.sleep(0.026)  # Wait for converter
    MSB = bus.read_byte_data(BMP180_ADDR, BMP180_PRESSUREDATA)
    LSB = bus.read_byte_data(BMP180_ADDR, BMP180_PRESSUREDATA + 1)
    XLSB = bus.read_byte_data(BMP180_ADDR, BMP180_PRESSUREDATA + 2)
    UP = ((MSB << 16) + (LSB << 8) + XLSB) >> (8 - OSS)

    # Calculate true pressure using calibration data
    B6 = B5 - 4000
    X1 = (cal['B2'] * ((B6 * B6) // (1 << 12))) // (1 << 11)
    X2 = (cal['AC2'] * B6) // (1 << 11)
    X3 = X1 + X2
    B3 = (((cal['AC1'] * 4 + X3) << OSS) + 2) // 4  # Ensure integer division

    X1 = (cal['AC3'] * B6) // (1 << 13)
    X2 = (cal['B1'] * ((B6 * B6) // (1 << 12))) // (1 << 16)
    X3 = ((X1 + X2) + 2) // (1 << 2)
    B4 = (cal['AC4'] * (X3 + 32768)) // (1 << 15)
    B7 = (UP - B3) * (50000 >> OSS)

    if B7 < 0x80000000:
        pressure = (B7 * 2) // B4
    else:
        pressure = (B7 // B4) * 2

    X1 = (pressure // (1 << 8)) * (pressure // (1 << 8))
    X1 = (X1 * 3038) // (1 << 16)
    X2 = (-7357 * pressure) // (1 << 16)
    pressure = pressure + ((X1 + X2 + 3791) // (1 << 4))

    return pressure  # In Pa


# Calculate altitude from pressure
def calculate_altitude(pressure, sea_level_pressure=101325.0):
    # Altitude calculation based on the barometric formula
    altitude = 44330.0 * (1.0 - (pressure / sea_level_pressure) ** 0.1903)
    return altitude


# Main loop to read data
def main():
    initialize_mpu6050()
    print("Reading MPU6050 and BMP180 data...")

    # Read calibration data from BMP180
    cal = read_bmp180_calibration_data()

    # You can set the sea-level pressure for your location (in Pascals)
    local_sea_level_pressure = 101325.0  # Adjust this based on your local sea-level pressure

    while True:
        # MPU6050 data
        acc_x, acc_y, acc_z = read_accelerometer_data()
        print(f"Accelerometer (g): X={acc_x:.2f}, Y={acc_y:.2f}, Z={acc_z:.2f}")

        # BMP180 data
        temp, B5 = read_bmp180_temperature(cal)
        pressure = read_bmp180_pressure(cal, B5)
        altitude = calculate_altitude(pressure, local_sea_level_pressure)

        print(f"BMP180: Temp={temp:.2f}°C, Pressure={pressure:.2f} Pa, Altitude={altitude:.2f} meters")

        time.sleep(1)


if __name__ == "__main__":
    main()

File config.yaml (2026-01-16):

# Fall Detection Project Configuration
# Override settings in config.local.yaml (not committed to git)

# Dataset paths for training
dataset:
  fall_folder: "./data/Fall"
  non_fall_folder: "./data/ADL"

# Raspberry Pi deployment paths
raspberry_pi:
  model_path: "/home/ivanursul/performer_model.pt"
  offsets_path: "/home/ivanursul/mpu_offsets.json"
  heatmap_path: "/home/ivanursul/heatmap_array.json"
  data_output_path: "/home/ivanursul/accelerometer_data_raw"

# Model constants (shared across all architectures)
model:
  max_sequence_length: 800
  input_dim: 4  # AccX, AccY, AccZ, Magnitude
  num_classes: 2  # Fall, Non-Fall
  csv_columns:
    - "AccX_filtered_i"
    - "AccY_filtered_i"
    - "Corrected_AccZ_i"
    - "Acc_magnitude_i"

# Hardware configuration
hardware:
  sampling_rate: 100  # Hz
  accel_range: 16  # g
  mpu6050_address: 0x68
  buzzer_pin: 23
  button_pin_1: 24
  button_pin_2: 25

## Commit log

2024-10-25 Fixed code in the data collector
    [main-box.scad, separator.scad]
2024-11-13 Pushing latest changes to Github
    [main-box.scad]
2024-11-14 Added script for measuring heart rate from ad8232 sensor
2025-01-23 Added a bunch of updates
    [Base Board.SchDoc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]
2026-01-16 Add deployment scripts for Raspberry Pi
    Three deployment scripts for different use cases:
    - deploy-fall-detector.sh: Production fall detection
    - deploy-adl-collector.sh: ADL data collection
    - deploy-fall-collector.sh: Fall data collection with heatmap
    Features:
    - Interactive prompts for Pi connection (IP, username, password)
    - Automatic dependency installation
    - Sensor calibration during deployment
    - Systemd service setup (auto-replaces existing service)
    - Only one mode active at a time
    Also updates README.md with deployment documentation.
2026-01-16 Add centralized logging with daily rotation
    - logging_config.py: Shared logging module with TimedRotatingFileHandler
    - Logs to ~/logs/fall-detection.log
    - Daily rotation with 30 days retention
    - Format: timestamp [script-name] level - message
    - Updated all Pi scripts to use proper logging:
    - fall-detector.py: INFO for status, WARNING for falls detected
    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
2026-01-16 Skip dependency installation if already installed
    Checks for existing packages before installing:
    - System packages: dpkg -s i2c-tools
    - Python packages: import torch; import performer_pytorch
    Speeds up repeated deployments significantly.
2026-01-16 Add consolidated cycle logging to fall detector
    Each 8-second cycle now logs:
    - Cycle number (sequential counter)
    - Classification result (FALL/ADL)
    - Inference time in milliseconds
    - Max acceleration magnitude in g
    Example: "Cycle 42: ADL | inference: 12.3ms | max_accel: 1.85g"
2026-01-16 Add redeploy scripts for quick updates
    Redeploy scripts skip dependencies and calibration:
    - redeploy-fall-detector.sh
    - redeploy-adl-collector.sh
    - redeploy-fall-collector.sh
    Just uploads files and restarts the service.
2026-01-16 Fix bash syntax error with RPi.GPIO package name
    Replace associative array with case statement to handle
    package names containing special characters (periods, hyphens).
2026-01-16 Add falling person ASCII animation to banner
    7-frame animation showing person losing balance and falling,
    plays when deployment scripts start.
2026-01-16 Fix swap setup to work without dphys-swapfile
    - Uses free command to check current swap
    - Creates /swapfile directly with fallocate/dd
    - Adds to /etc/fstab for persistence
    - Works on any Linux system
2026-01-16 Add clearer status messages for package checks
    Shows:
    ✓ pkg (installed) - already available
    ✗ pkg (missing) - installing...
2026-01-16 Skip calibration if already calibrated
    Checks for mpu_offsets.json on Pi. If found, asks:
    Re-calibrate? [y/N]
    Default is N, so pressing Enter skips calibration.
2026-01-16 Fix model hyperparameters to match trained checkpoint
    Changed:
    - hidden_dim: 16 → 128
    - num_layers: 1 → 4
    These must match the saved performer_model.pt weights.
    [fall-detector.py]
2026-01-16 Add service file update to redeploy scripts
    Redeploy scripts now also update the systemd service file,
    ensuring User and PYTHONPATH settings are always current.
